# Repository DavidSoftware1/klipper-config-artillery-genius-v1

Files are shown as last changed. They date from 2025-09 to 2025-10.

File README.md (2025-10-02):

<p align="center">
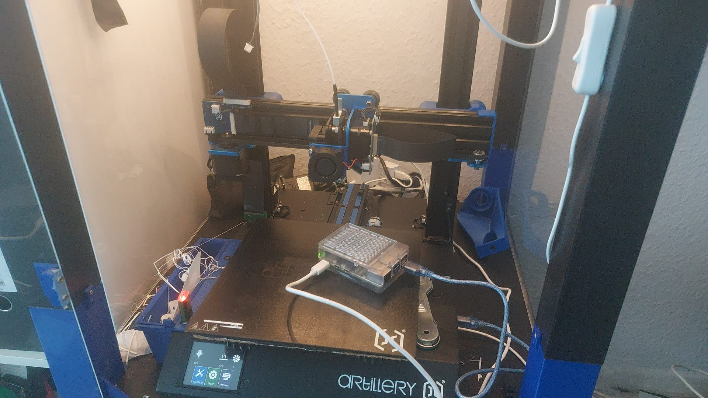
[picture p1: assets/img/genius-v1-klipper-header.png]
Artillery Genius Klipper Konfiguration Header
  
</p>

<h1 align="center">🚀 Artillery Genius V1 - Klipper Configuration</h1>

<p align="center">
  <strong>Complete Klipper setup for Artillery Genius V1 with MKS Gen L board</strong>
  <br/>
  <em>Mit deutschen Makros und Troubleshooting-Guide - Getestet und dokumentiert!</em>
</p>

<p align="center">
  
  
  
  
</p>

## 📖 Inhaltsverzeichnis

- [✨ Meine Erfolgsstory](#-meine-erfolgsstory)
- [🛠️ Komplette Installationsanleitung](#️-komplette-installationsanleitung)
- [🔧 Kritische Probleme & Lösungen](#-kritische-probleme--lösungen)
- [📁 Dateistruktur](#-dateistruktur)
- [🎮 Makros & Funktionen](#-makros--funktionen)
- [🐛 Problembehebung](#-problembehebung)
- [🤝 Mitwirken](#-mitwirken)

## ✨ Meine Erfolgsstory

### 🎯 Von Marlin zu Klipper: Komplette Hardware- und Performance-Optimierung für den Artillery Genius V1

Was als scheinbar unkompliziertes Upgrade begann, entwickelte sich zu einem tiefgreifenden Optimierungsprojekt, um das volle Potenzial des Artillery Genius V1 auszuschöpfen. Dieses Repository liefert die vollständige und getestete Klipper-Konfiguration für Boards mit dem MKS Gen L (ATmega2560).

Die Konfiguration löst nicht nur gängige Pin-Mapping-Probleme und behebt Inkompatibilitäten, sondern implementiert auch erweiterte Klipper-Funktionen (wie Input Shaping und Pressure Advance). Das Ergebnis ist eine dramatische Steigerung der Druckgeschwindigkeit, Stabilität und – vor allem – der Druckqualität, die weit über die Möglichkeiten der Standard-Marlin-Firmware hinausgeht. Holen Sie jetzt das Maximum aus Ihrem Artillery Genius V1 heraus.

### 📊 Meine Hardware
- **Drucker**: Artillery Genius V1
- **Mainboard**: MKS Gen L (ATmega2560)
- **Host**: Raspberry Pi 5
- **Schnittstelle**: USB über CH340 (COM6)

## 🛠️ Komplette Installationsanleitung

### Schritt 1: Basis-Setup & KIAUH
```bash
# System vorbereiten
sudo apt update && sudo apt upgrade -y
sudo apt-get install git -y

# KIAUH installieren
git clone https://github.com/th33xitus/kiauh.git
./kiauh/kiauh.sh

| **`Artillery-Genius-V1-Klipper/`** | | **Das Hauptverzeichnis des Projekts.** |
| ├── 📄 **`README.md`** | | **Diese Datei.** Beinhaltet die Installationsanleitung und Projektdetails. |
| ├── 📁 **`klipper/`** | | **Die Klipper-Core-Dateien.** |
| │ ├── 📄 `klipper.elf.hex` | MCU Firmware | Die fertig kompilierte Klipper-Firmware für das **MKS Gen L (ATmega2560) Mainboard** des Druckers. |
| │ └── 📁 `config/` | Klipper-Konfigurationen | Alle `.cfg`-Dateien zur Definition des Druckers. |
| │ ├── 📄 `printer.cfg` | **Hauptkonfiguration** | Definiert alle Pins, Kinematik und die kalibrierten Basiswerte. |
| │ ├── 📄 `macros.cfg` | Makros | Alle Makros wie `PRINT_START`, `END_PRINT` und sonstige Komfort-Funktionen. |
| │ ├── 📄 `end.cfg` | Druckende-Routinen | Routinen für den Abschluss eines Drucks. |
| │ └── 📄 `klipperscreen.cfg` | Display-Einstellungen | Voreinstellungen für das KlipperScreen-Interface. |
| ├── 📁 **`Prusa/`** | | **Slicer-Profile und Modelle.** |
| │ ├── 📄 `config.ini` | PrusaSlicer Profil | Das exportierte Profil, abgestimmt auf die Klipper-Geschwindigkeiten. |
| │ └── 📁 `3d/` | Modelle | Enthält Kalibrierungs-Modelle (`.stl`) und Projektdateien (`.3mf`). |
| ├── 📁 **`Marlin-bugfix-2.1.x/`** | | **Fallback-Firmware & Referenz.** |
| │ ├── 📄 `_Bootscreen.h` | Custom Bootscreen | Die Datei für den benutzerdefinierten Bootscreen-Startbildschirm. |
| │ └── 📄 `config.ini` | Marlin Basis-Config | Die Konfigurations-Dateien der ursprünglich verwendeten Marlin-Version. |
| └── 📁 **`assets/`** | | **Ressourcen und Dokumentation.** |
| └── 📄 `genius-v1-klipper-header.png` | Header-Bild | Das Bild, das oben in dieser README angezeigt wird. |
| └── 📄 `klipper-installation-doku.pdf` | Dokumentation | Die detaillierte Schritt-für-Schritt-Installationsanleitung im PDF-Format. |

## ⚡ Schnellstart

### 1. Klipper Installation
```bash
# Mit KIAUH installieren
git clone https://github.com/th33xitus/kiauh.git
./kiauh/kiauh.sh
# Wähle: Klipper → Moonraker → Mainsail

2. Firmware Flashen
bash

# Auf dem Raspberry Pi
cd ~/klipper
make menuconfig
# Micro-controller: Atmega AVR
# Processor: atmega2560
# Communication: UART0
make

# Flashen mit korrektem Device
make flash FLASH_DEVICE=/dev/serial/by-id/usb-1a86_USB_Serial-if00-port0

3. Konfiguration übernehmen
bash

# printer.cfg nach ~/printer_data/config/ kopieren
# Seriellen Pfad anpassen:
[mcu]
serial: /dev/serial/by-id/usb-1a86_USB_Serial-if00-port0

4. PrusaSlicer Profile

    Prusa/config.ini importieren

    G-code Flavor: Klipper

    Start/End G-code anpassen

🔧 Wichtige Fixes
🌀 Lüfter-Probleme Gelöst

Problem: Hotend-Lüfter (24V) reagierte nicht auf Pin ar7

Lösung: Korrekte Pin-Definition im [board_pins] Block:
ini

[board_pins arduino-mega]
aliases:
    ar5=PE3,    # Grüne LED
    ar6=PH3,    # Blaue LED  
    ar7=PH4,    # Hotend Lüfter (24V) - FIXED!
    ar9=PH6,    # Bauteil Lüfter

💡 LED-Steuerung

Problem: Neopixel flackerte unkontrolliert

Lösung: Einfache Output-Pins verwenden:

[output_pin green_led]
pin: ar5
value: 1

[output_pin blue_led]
pin: ar6  
value: 1

🎮 Makros & Funktionen
🏠 Smart Home
gcode

SMARTHOME          ; Homing 
MOVE_CENTER        ; Zur Bettmitte fahren

⏸️ Drucksteuerung
gcode

PAUSE              ; Sichere Unterbrechung
RESUME             ; Exaktes Fortsetzen
CANCEL_PRINT       ; Geordneter Abbruch

🎨 LED Status
gcode

LED_GRUEN          ; Bereit
LED_BLAU           ; Pausiert
LED_ROT            ; Fehler
LED_WEISS          ; Druck läuft

🔥 Kalibrierung
gcode

PID_EXTRUDER TARGET=210    ; Hotend PID
PID_BED TARGET=60          ; Heatbed PID

🔄 Marlin Fallback

Falls Klipper nicht wie gewünscht funktioniert, steht ein Marlin Fallback bereit:
Marlin Konfiguration

    Location: Marlin-bugfix-2.1.x/

    Custom Bootscreen in _Bootscreen.h

    Basierend auf: Offizielle Artillery Configs

Kompilieren mit PlatformIO
bash

cd Marlin-bugfix-2.1.x
platformio run -e mega2560
platformio run --target upload --upload-port COM6

🐛 Problembehebung
Häufige Probleme
Problem	Lösung
Serial Connection Failed	ls /dev/serial/by-id/ prüfen
Fans not working	24V am Hotend-Lüfter prüfen
LEDs flickering	[output_pin] statt [neopixel] verwenden
Flash Timeout	PrusaSlicer Firmware Flasher nutzen
Debug Commands
bash

# Serielle Verbindung prüfen
ls /dev/serial/by-id/

# Klipper Status
sudo service klipper status

# Logs anzeigen
tail -f ~/printer_data/logs/klippy.log

📸 Screenshots

(Füge hier deine Screenshots hinzu)

    Mainsail Dashboard

    Erfolgreicher Benchy-Druck

    LED-Steuerung in Aktion

    KlipperScreen Interface

🎯 Nächste Schritte

    Crowsnest für Webcam-Stream installieren

    Pressure Advance kalibrieren

    Input Shaping konfigurieren

    Timelapse mit Moonraker einrichten

🤝 Mitwirken

Fehler gefunden? Verbesserungsvorschläge?

    Repository forken

    Feature-Branch erstellen

    Änderungen committen

    Pull Request stellen

📄 Lizenz

MIT License - Frei verwendbar und modifizierbar für dein Artillery Genius V1.

Viel Erfolg beim Drucken! 🎉

Wenn diese Konfiguration dir geholfen hat, gib dem Repository einen ⭐ Stern!

Wichtiger Hinweis: Diese Konfiguration wurde speziell für den Artillery Genius V1 mit MKS Gen L Board entwickelt. Bei anderen Modellen sind Anpassungen notwendig.
text

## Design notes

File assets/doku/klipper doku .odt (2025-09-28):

sudo apt update && sudo apt upgrade -y && sudo apt autoremove -y &&sudo reboot

5min trotz lan 1000mbit

sudo apt-get install git -y

git clone https://github.com/th33xitus/kiauh.git
./kiauh/kiauh.sh

KIAUH v6.0.0-alpha1 is available now! |

| View Changelog: https://git.io/JnmlX |

| KIAUH v6 was completely rewritten from the ground up. |

| It's based on Python 3.8 and has many improvements. |

| NOTE: Version 6 is still in alpha, so bugs may occur! |

| Yet, your feedback and bug reports are very much |

| appreciated and will help finalize the release. |

| Would you like to try out KIAUH v6? |

| 1) Yes |

| 2) No |

| 3) Yes, remember my choice for next time |

| 4) No, remember my choice for next time |

| Q) Quit |

\=======================================================/

###### Select action:

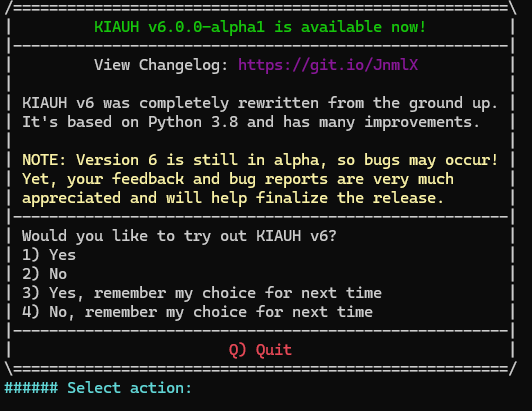
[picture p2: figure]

Gib bitte die Zahl 2 ein und drücke Enter

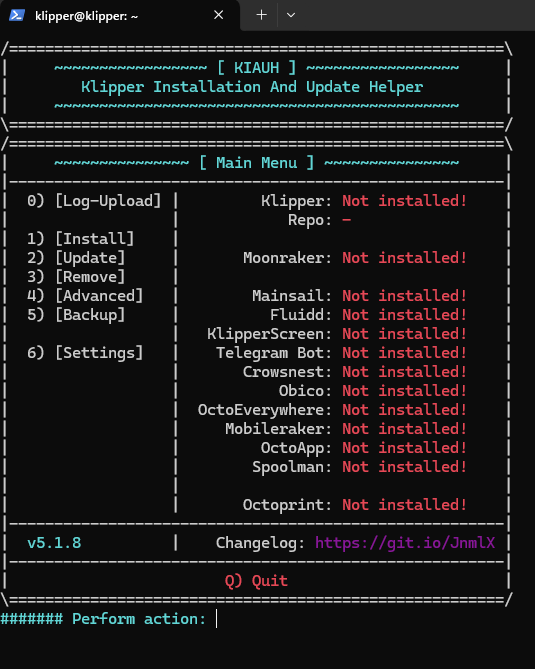
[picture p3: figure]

Nachdem du das getan hast, sollte das Hauptmenü erscheinen. Dort musst du dann 1) Install auswählen, um die Klipper-Komponenten zu installieren.

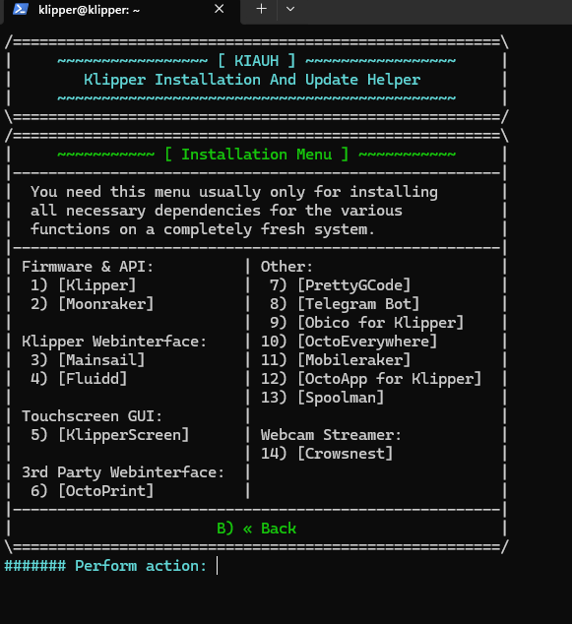
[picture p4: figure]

### Mein Tipp:

Um jetzt nicht den Überblick zu verlieren, installiere zuerst die absoluten Grundlagen: Klipper, Moonraker und Mainsail.

Gib also wie gesagt 1, ein und drücke Enter, um die Installation zu starten.

### Was bedeuten die anderen Optionen?

- 5) KlipperScreen: Dies ist für Leute, die einen Touchscreen direkt am Raspberry Pi angeschlossen haben, um den Drucker ohne Laptop oder Handy zu steuern. Da du eine Weboberfläche nutzen willst, brauchst du das nicht.
- 6) OctoPrint: Dies ist eine alternative Benutzeroberfläche zu Mainsail. Du solltest dich für eine der beiden entscheiden. Da wir bereits Mainsail empfohlen haben, kannst du OctoPrint ignorieren.
- 7) PrettyGCode: Eine Erweiterung für die Benutzeroberfläche, die dir den G-Code optisch aufbereitet. Ein nettes Gimmick.
- 8) Telegram Bot, 9) Obico, 10) OctoEverywhere, 11) Mobileraker, 12) OctoApp: Das sind alles Dienste, die dir helfen, deinen Drucker auch von unterwegs aus zu steuern und zu überwachen (oft mit Smartphone-Apps). Das sind Features für später.
- 13) Spoolman: Ein Tool, um deinen Filamentbestand zu verwalten. Das hat nichts direkt mit dem Drucken zu tun.
- 14) Crowsnest: Das ist der Webcam-Streamer, den du brauchst, um deine Pi-Kamera einzubinden. Das ist eine sehr nützliche Erweiterung, die wir später installieren können, wenn die Grundfunktionen laufen.

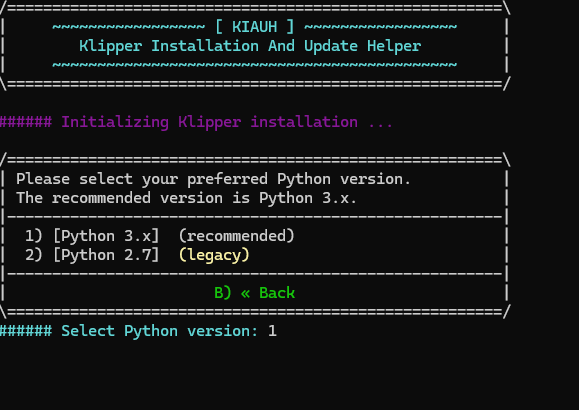
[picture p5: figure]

Python 3.x ist die richtige Wahl.

1 drunker haben wir 5min trotz lan 1000mbit

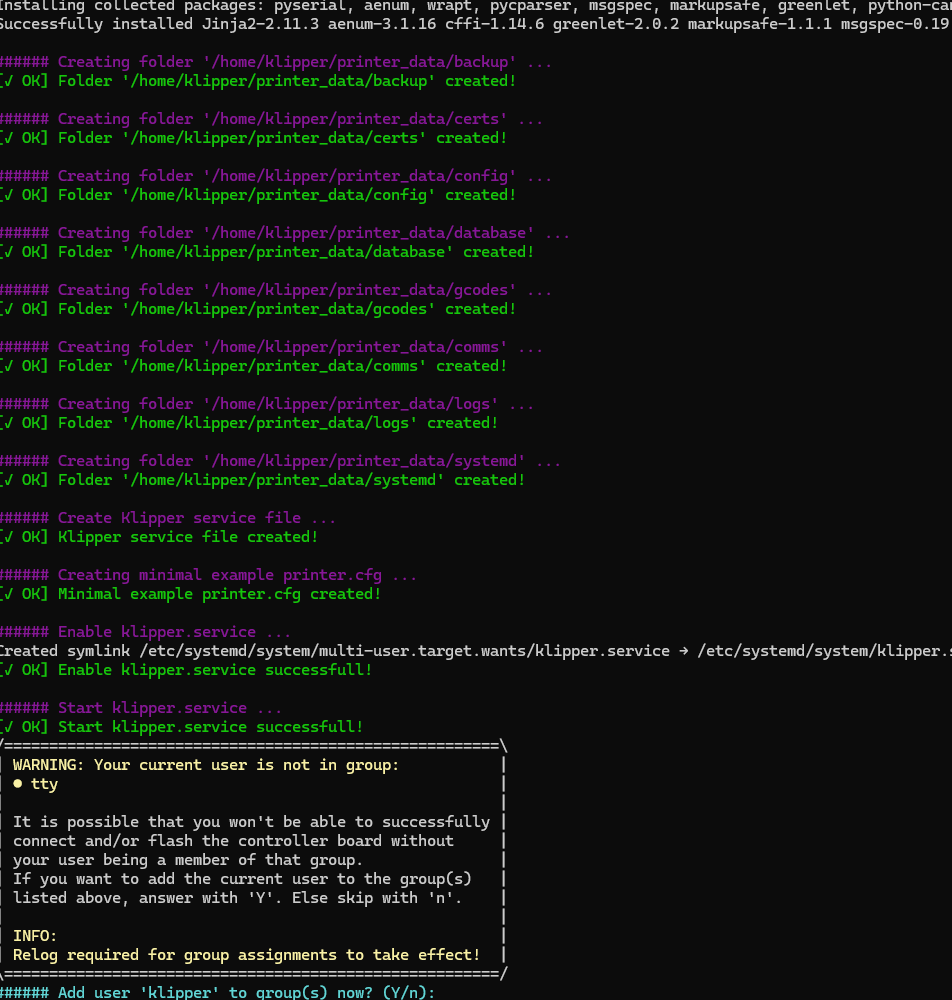
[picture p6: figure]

dvsvdv

a, gib Y ein und drücke Enter.

Das ist wichtig, damit der Klipper-Benutzer auf die Hardware-Schnittstelle deines Druckers zugreifen kann. Das Hinzufügen zu dieser Gruppe verhindert Verbindungsprobleme.

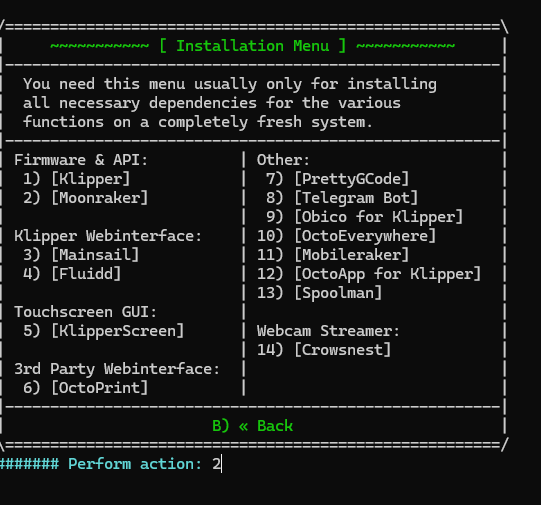
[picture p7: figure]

Moonraker (2): Dies ist die Schnittstelle (der "Dolmetscher"), die es deinem Pi ermöglicht, mit Klipper zu kommunizieren und ihm Befehle zu senden. Ohne Moonraker kann Klipper nicht gesteuert werden.

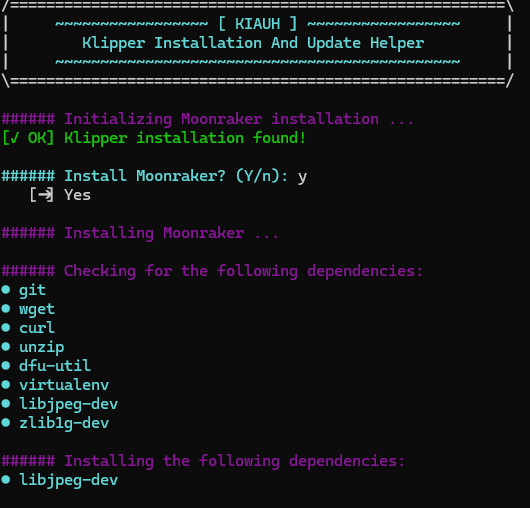
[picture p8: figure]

gfdgfdbsolut richtig! Jetzt kommt die Installation von Mainsail.

### Installation von Mainsail

Gib jetzt 3 ein und drücke Enter, um die Mainsail-Oberfläche zu installieren.

Moonraker ist die "Sprache", die Klipper und Mainsail verbindet. Mainsail ist das "Gesicht", das du im Browser siehst. Du brauchst beide, um deinen Drucker zu steuern.

Lass die Installation jetzt durchlaufen. Wenn sie abgeschlossen ist, sind alle notwendigen Komponenten auf deinem Raspberry Pi installiert.

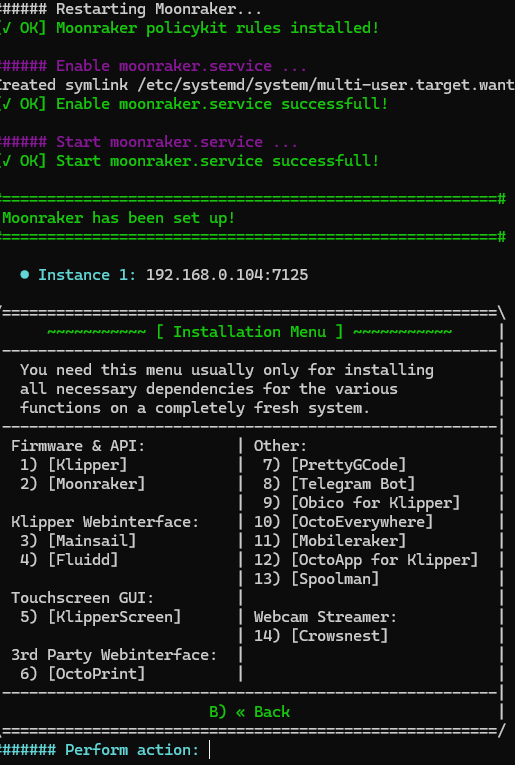
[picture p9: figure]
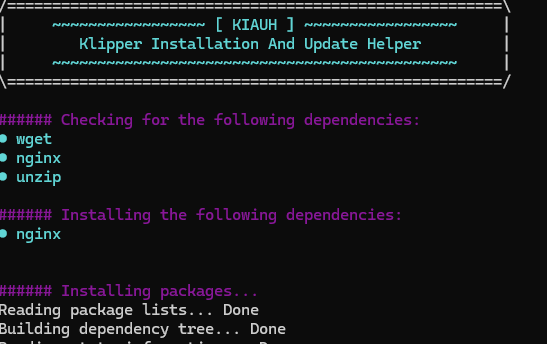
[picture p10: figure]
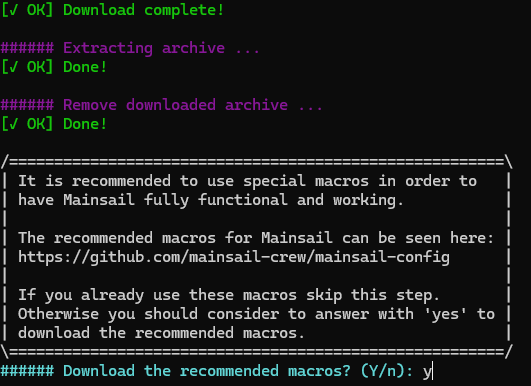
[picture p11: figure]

Y

Glückwunsch! Alle notwendigen Komponenten sind jetzt auf deinem Raspberry Pi installiert und einsatzbereit. Das ist der größte Teil der Arbeit.

Verlasse das KIAUH-Menü, indem du b enter q enter eingibst und Enter drückst.

cd ~/klipper

nun den drucker anstecken

ls /dev/serial/by-id/*

in meinem fall /dev/serial/by-id/usb-1a86_USB_Serial-if00-port0

Wenn alles korrekt angeschlossen ist, sollte jetzt ein Gerätename wie /dev/serial/by-id/usb-1a86_USB_Serial-if00-port0 erscheinen. Wenn du den Gerätenamen hast,

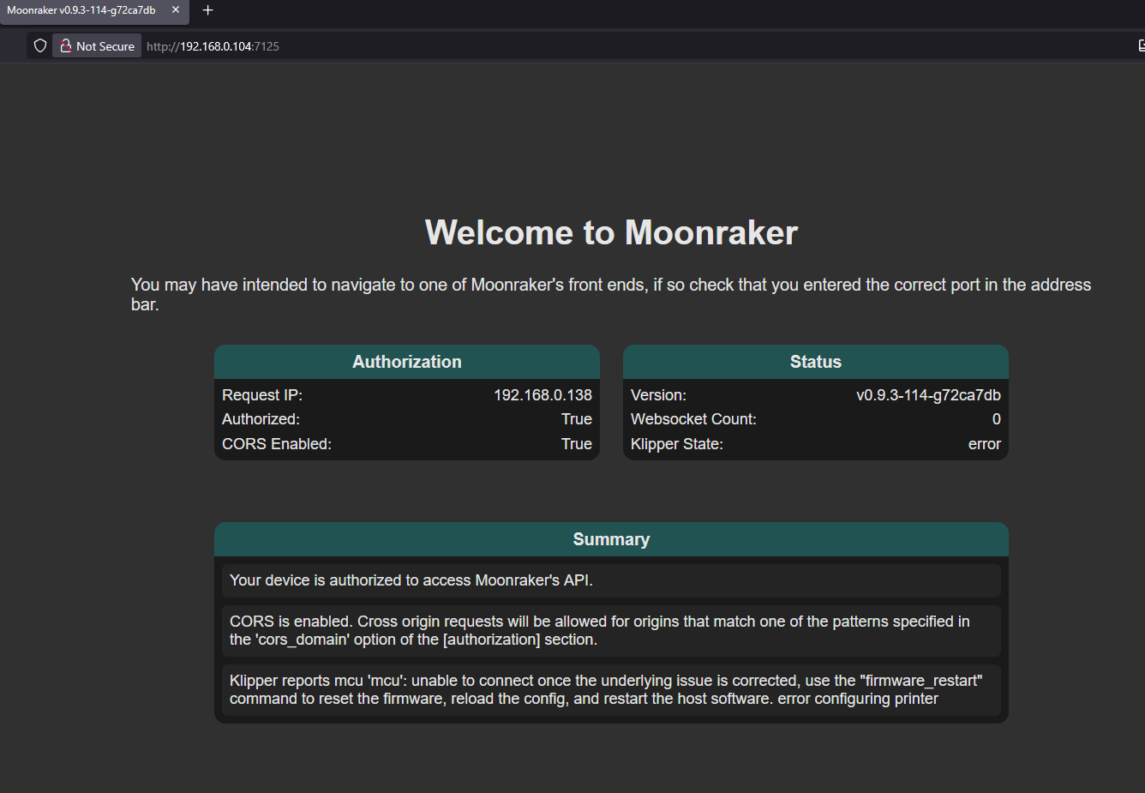
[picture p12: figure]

sudo service klipper stop

klipper@klipper:~/klipper $ make menuconfig

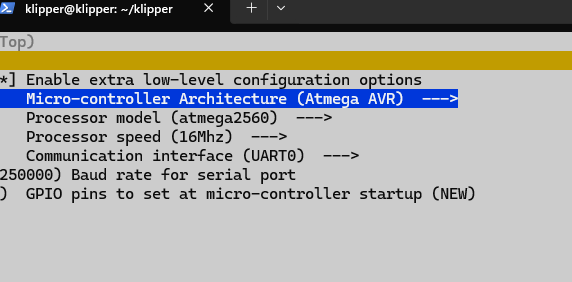
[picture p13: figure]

scsac

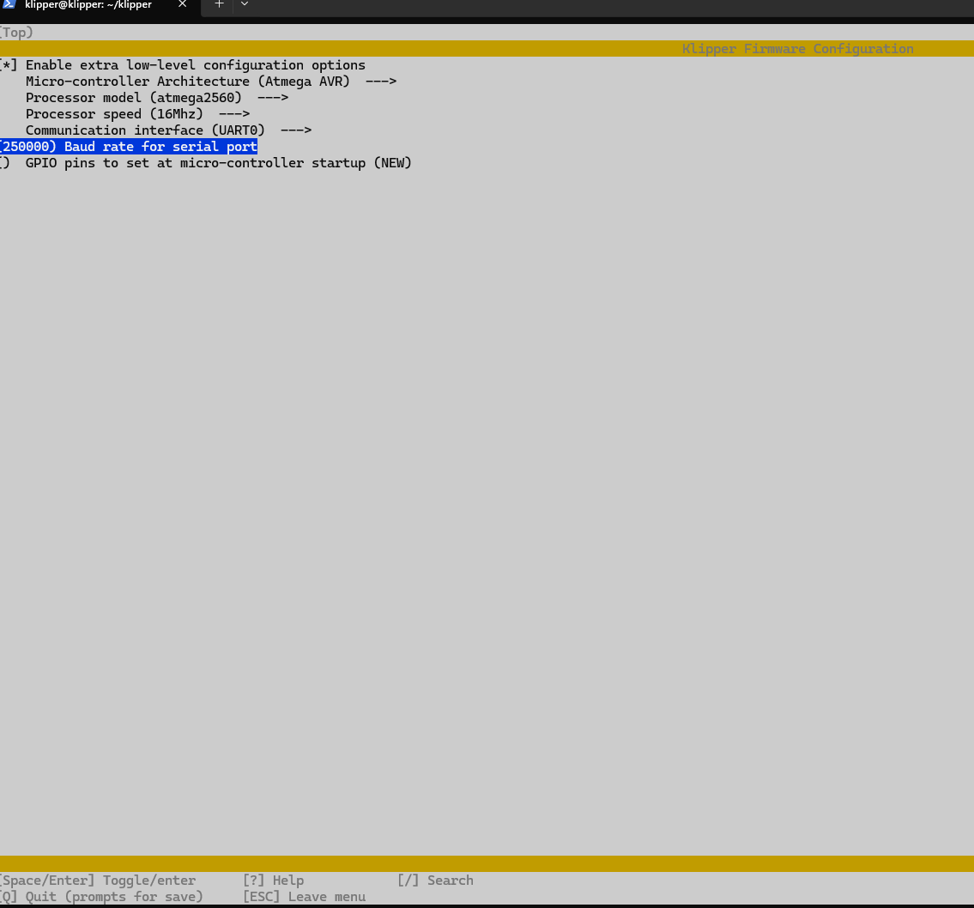
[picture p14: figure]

make

klipper@klipper:~/klipper $ ls /dev/serial/by-id/*

/dev/serial/by-id/usb-1a86_USB_Serial-if00-port0

make flash FLASH_DEVICE=/dev/serial/by-id/usb-1a86_USB_Serial-if00-port0

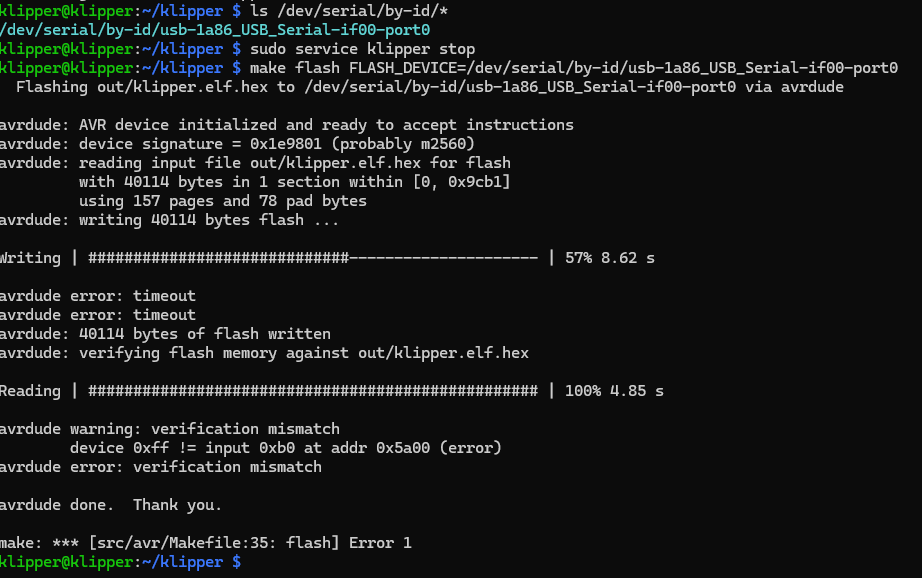
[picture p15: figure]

sudo service klipper start

sudo service klipper stop

avrdude -p atmega2560 -c wiring -P /dev/serial/by-id/usb-1a86_USB_Serial-if00-port0 -b115200 -D -U flash:w:out/klipper.elf.hex:i nop

sudo avrdude -p atmega2560 -c arduino -P /dev/serial/by-id/usb-1a86_USB_Serial-if00-port0 -b 115200 -U flash:w:out/klipper.elf.hex:i

sudo service klipper stop

klipper@klipper:~/klipper $ make flash FLASH_DEVICE=/dev/serial/by-id/usb-1a86_USB_Serial-if00-port0

Flashing out/klipper.elf.hex to /dev/serial/by-id/usb-1a86_USB_Serial-if00-port0 via avrdude

avrdude: AVR device initialized and ready to accept instructions

avrdude: device signature = 0x1e9801 (probably m2560)

avrdude: reading input file out/klipper.elf.hex for flash

with 40114 bytes in 1 section within [0, 0x9cb1]

using 157 pages and 78 pad bytes

avrdude: writing 40114 bytes flash ...

Writing | #############################--------------------- | 57% 8.62 s

avrdude error: timeout

avrdude error: timeout

avrdude: 40114 bytes of flash written

avrdude: verifying flash memory against out/klipper.elf.hex

Reading | ################################################## | 100% 4.85 s

avrdude warning: verification mismatch

device 0xff != input 0xb0 at addr 0x5a00 (error)

avrdude error: verification mismatch

avrdude done. Thank you.

make: *** [src/avr/Makefile:35: flash] Error 1

klipper@klipper:~/klipper $ sudo service klipper start

klipper@klipper:~/klipper $ make menuconfig

Loaded configuration '/home/klipper/klipper/.config'

No changes to save (for '/home/klipper/klipper/.config')

klipper@klipper:~/klipper $ avrdude -p atmega2560 -c wiring -P /dev/serial/by-id/usb-1a86_USB_Serial-if00-port0 -b115200 -D -U flash:w:out/klipper.elf.hex:i

avrdude: AVR device initialized and ready to accept instructions

avrdude: device signature = 0x1e9801 (probably m2560)

avrdude: reading input file out/klipper.elf.hex for flash

with 40114 bytes in 1 section within [0, 0x9cb1]

using 157 pages and 78 pad bytes

avrdude: writing 40114 bytes flash ...

Writing | ###############----------------------------------- | 29% 6.91 s

avrdude error: timeout

avrdude error: timeout

avrdude: 40114 bytes of flash written

avrdude: verifying flash memory against out/klipper.elf.hex

Reading | ################################################## | 100% 4.86 s

avrdude warning: verification mismatch

device 0xff != input 0x8e at addr 0x2f00 (error)

avrdude error: verification mismatch

avrdude done. Thank you.

klipper@klipper:~/klipper $ sudo avrdude -p atmega2560 -c arduino -P /dev/serial/by-id/usb-1a86_USB_Serial-if00-port0 -b 115200 -U flash:w:out/klipper.elf.hex:i

avrdude error: programmer is not responding

avrdude warning: attempt 1 of 10: not in sync: resp=0x00

avrdude error: programmer is not responding

avrdude warning: attempt 2 of 10: not in sync: resp=0x00

avrdude error: programmer is not responding

avrdude warning: attempt 3 of 10: not in sync: resp=0x00

avrdude error: programmer is not responding

ok jetzt mit video unter stützung von https://www.youtube.com/watch?v=7iQK6uSapJ0&t=485s

https://drive.google.com/file/d/1XB76P_dJ4WT7VyK5eNJ-UQJnxc4sq9R0/view

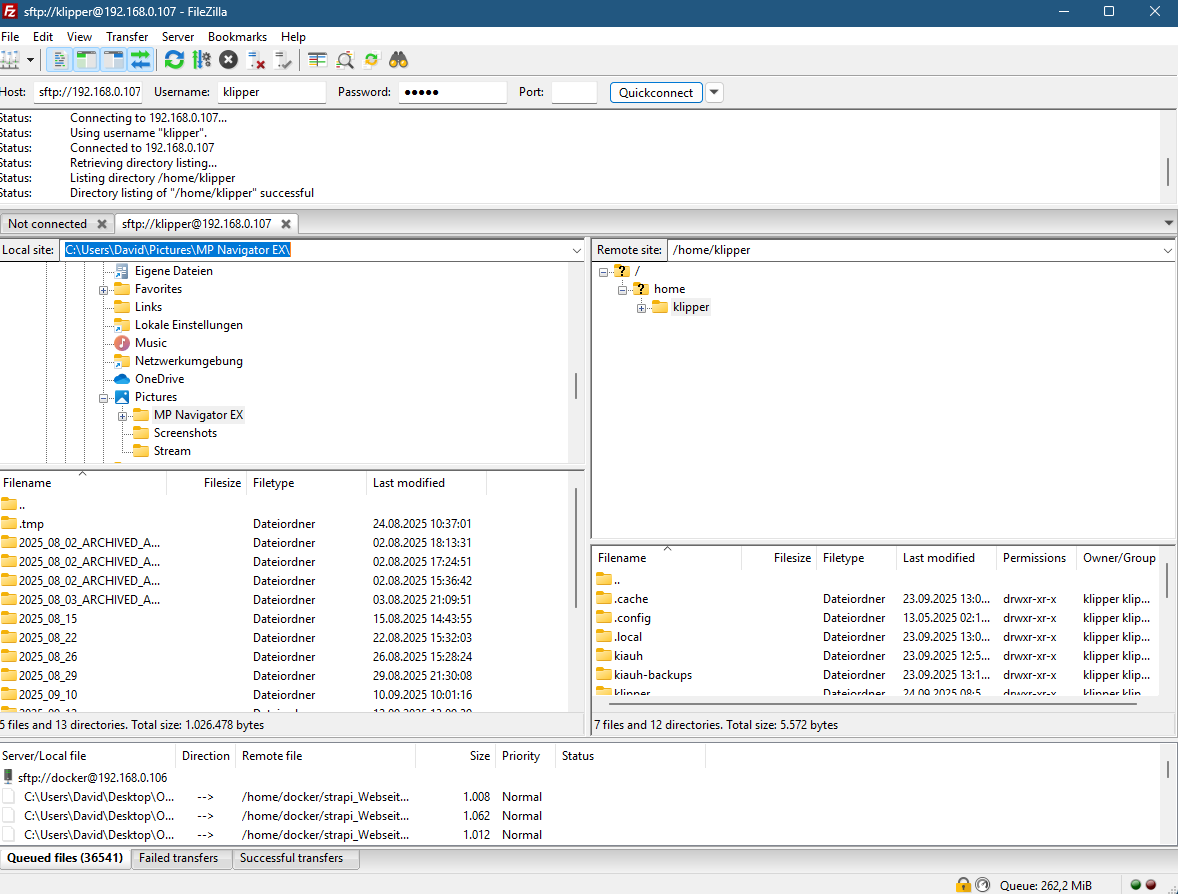
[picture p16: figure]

also file zilla auf und los git clone https://github.com/kliment/Printrun.git https://www.youtube.com/watch?v=7iQK6uSapJ0&t=485s

drucker an pc anschliessen vill erfolg ?

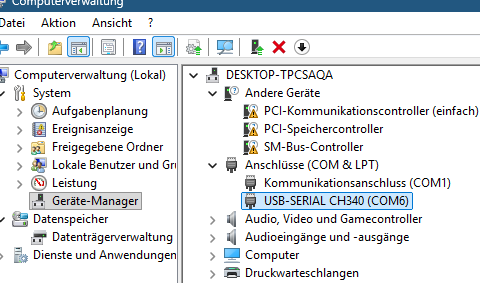
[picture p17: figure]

Cdc

also com 4 also avrdude -p atmega2560 -c arduino -P COM4 -b 115200 -U flash:w:klipper.elf.hex:i

also vs code aud plattform io installiren datai in ordner schmeissen offenen vertrauen dann quik acsess →miscellanous plattform io core cli cd .platformio

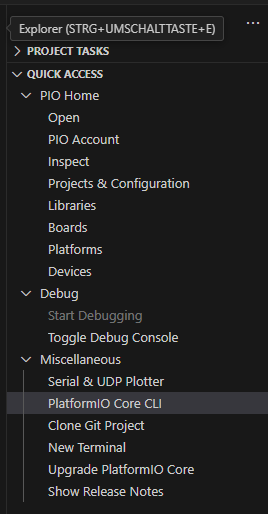
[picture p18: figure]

PS C:\Users\David\.platformio> ls

Directory: C:\Users\David\.platformio

Mode LastWriteTime Length Name

d---- 24.09.2025 10:48 .cache

d---- 24.09.2025 10:45 packages

d---- 24.09.2025 10:45 penv

d---- 24.09.2025 10:44 python3

-a--- 24.09.2025 10:45 177 appstate.json

PS C:\Users\David\.platformio> cd packages

PS C:\Users\David\.platformio\packages> ls

Directory: C:\Users\David\.platformio\packages

Mode LastWriteTime Length Name

d---- 24.09.2025 10:45 contrib-piohome

PS C:\Users\David\.platformio\packages> also nach installation von pio platform install atmelavr

S C:\Users\David\.platformio\packages> pio platform install atmelavr

WARNING: This command is deprecated and will be removed in the next releases.

Please use `pio pkg install` instead.

Platform Manager: Installing atmelavr

Downloading [####################################] 100%

Unpacking [####################################] 100%

Platform Manager: atmelavr@5.1.0 has been installed!

Tool Manager: Installing platformio/toolchain-atmelavr @ ~1.70300.0

Downloading [####################################] 100%

Unpacking [####################################] 100%

Tool Manager: toolchain-atmelavr@1.70300.191015 has been installed!

PS C:\Users\David\.platformio\packages> & "C:\Users\David\.platformio\packages\toolchain-atmelavr\bin\avrdude.exe" -C "C:\Users\David\.platformio\packages\toolchain-atmelavr\etc\avrdude.conf" -v -p atmega2560 -c arduino -P COM4 -b 115200 -U flash:w:C:\Users\David\Desktop\klipper\firmware.elf.hex:i

&: The term 'C:\Users\David\.platformio\packages\toolchain-atmelavr\bin\avrdude.exe' is not recognized as a name of a cmdlet, function, script file, or executable program.

Check the spelling of the name, or if a path was included, verify that the path is correct and try again.

PS C:\Users\David\.platformio\packages>

ls

Directory: C:\Users\David\.platformio\packages\toolchain-atmelavr

Mode LastWriteTime Length Name

d---- 24.09.2025 11:00 avr

d---- 24.09.2025 11:00 bin

d---- 24.09.2025 11:00 i686-w64-mingw32

d---- 24.09.2025 11:00 include

d---- 24.09.2025 11:00 lib

d---- 24.09.2025 11:00 libexec

-a--- 24.09.2025 11:00 185 .piopm

-a--- 13.12.2024 14:43 390 package.json

PS C:\Users\David\.platformio\packages\toolchain-atmelavr> cd bin

PS C:\Users\David\.platformio\packages\toolchain-atmelavr\bin> .\avrdude.exe -C "C:\Users\David\.platformio\packages\toolchain-atmelavr\etc\avrdude.conf" -v -p atmega2560 -c arduino -P COM4 -b 115200 -U flash:w:C:\Users\David\Desktop\klipper\firmware.elf.hex:i

antwort .\avrdude.exe: The term '.\avrdude.exe' is not recognized as a name of a cmdlet, function, script file, or executable program.

Check the spelling of the name, or if a path was included, verify that the path is correct and try again.

Auch im cmd probiert Microsoft Windows [Version 10.0.26100.6584]

(c) Microsoft Corporation. Alle Rechte vorbehalten.

C:\Users\David>cd "C:\Users\David\.platformio\packages\toolchain-atmelavr\bin"

C:\Users\David\.platformio\packages\toolchain-atmelavr\bin>avrdude.exe -C "C:\Users\David\.platformio\packages\toolchain-atmelavr\etc\avrdude.conf" -v -p atmega2560 -c arduino -P COM4 -b 115200 -U flash:w:C:\Users\David\Desktop\klipper\firmware.elf.hex:i

Der Befehl "avrdude.exe" ist entweder falsch geschrieben oder

konnte nicht gefunden werden.

C:\Users\David\.platformio\packages\toolchain-atmelavr\bin>ls

Der Befehl "ls" ist entweder falsch geschrieben oder

konnte nicht gefunden werden.

C:\Users\David\.platformio\packages\toolchain-atmelavr\bin>dir

Volume in Laufwerk C: hat keine Bezeichnung.

Volumeseriennummer: A4CE-B767

Verzeichnis von C:\Users\David\.platformio\packages\toolchain-atmelavr\bin

24.09.2025 11:00 <DIR> .

24.09.2025 11:00 <DIR> ..

12.03.2019 10:30 608.256 avr-addr2line.exe

12.03.2019 10:30 630.784 avr-ar.exe

12.03.2019 10:30 815.104 avr-as.exe

12.03.2019 10:46 877.568 avr-c++.exe

12.03.2019 10:30 605.696 avr-c++filt.exe

12.03.2019 10:46 876.032 avr-cpp.exe

12.03.2019 10:30 35.840 avr-elfedit.exe

12.03.2019 10:46 877.568 avr-g++.exe

12.03.2019 10:46 874.496 avr-gcc-7.3.0.exe

12.03.2019 10:46 52.736 avr-gcc-ar.exe

12.03.2019 10:46 52.736 avr-gcc-nm.exe

12.03.2019 10:46 53.248 avr-gcc-ranlib.exe

12.03.2019 10:46 874.496 avr-gcc.exe

12.03.2019 10:46 438.272 avr-gcov-dump.exe

12.03.2019 10:46 483.328 avr-gcov-tool.exe

12.03.2019 10:46 523.776 avr-gcov.exe

12.03.2019 10:53 3.299.840 avr-gdb.exe

12.03.2019 10:30 667.648 avr-gprof.exe

12.03.2019 10:30 1.102.848 avr-ld.bfd.exe

12.03.2019 10:30 1.102.848 avr-ld.exe

12.03.2019 10:50 1.944 avr-man

12.03.2019 10:30 617.472 avr-nm.exe

12.03.2019 10:30 766.976 avr-objcopy.exe

12.03.2019 10:30 888.832 avr-objdump.exe

12.03.2019 10:30 630.784 avr-ranlib.exe

12.03.2019 10:30 456.192 avr-readelf.exe

12.03.2019 10:30 616.448 avr-size.exe

12.03.2019 10:30 608.256 avr-strings.exe

12.03.2019 10:30 767.488 avr-strip.exe

12.03.2019 10:53 978.432 libiconv-2.dll

12.03.2019 10:53 51.694 libwinpthread-1.dll

31 Datei(en), 21.237.638 Bytes

2 Verzeichnis(se), 45.501.906.944 Bytes frei

C:\Users\David\.platformio\packages\toolchain-atmelavr\bin>

klappt auch nicht wir weden nun Arduino IDE testen

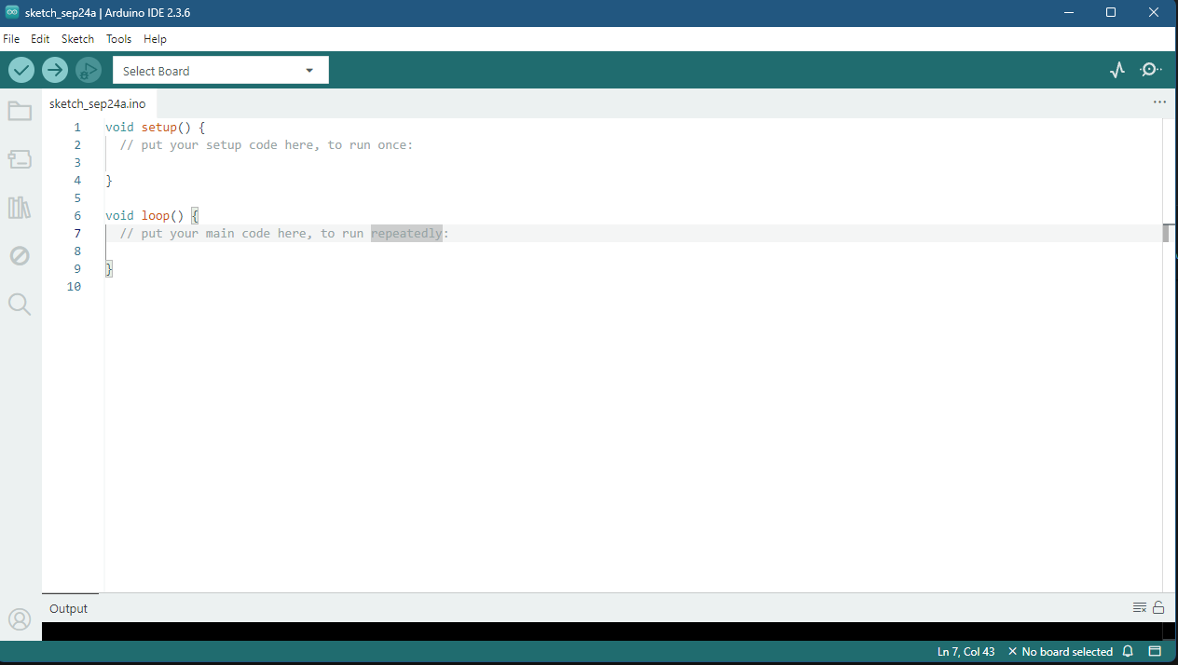
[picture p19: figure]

https://www.arduino.cc/en/software/

wo wir dabai sind der step back ist ja auch immer ein guter plan

https://github.com/MarlinFirmware/Configurations/tree/bugfix-2.1.x/config/examples/Artillery/Genius/V1

wichtig !

NotPlatformIOProjectError: Not a PlatformIO project. `platformio.ini` file has not been found in current working directory (C:\Users\David\Downloads\Marlin-bugfix-2.1.x). To initialize new project please use `platformio project init` command

platformio run

_Bootscreen.h

mega2560 SUCCESS 00:00:44.029

================================================================================================= 1 succeeded in 00:00:44.029 =================================================================================================

PS C:\Users\David\Downloads\Marlin-bugfix-2.1.x\Marlin-bugfix-2.1.x>

platformio run --target upload --upload-port COM6

nvironment Status Duration

mega2560 SUCCESS 00:00:30.954

================================================================================================= 1 succeeded in 00:00:30.954 =================================================================================================

PS C:\Users\David\Downloads\Marlin-bugfix-2.1.x\Marlin-bugfix-2.1.x>

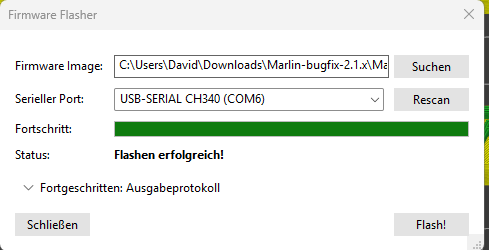
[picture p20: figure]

des

also versuchen wir mal die hex datai per prusa dadrauf zu bekommen !

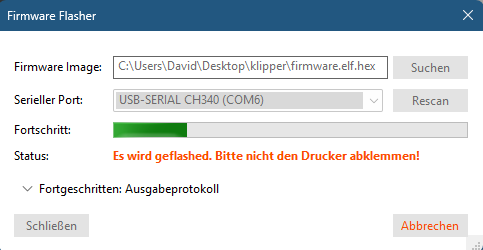
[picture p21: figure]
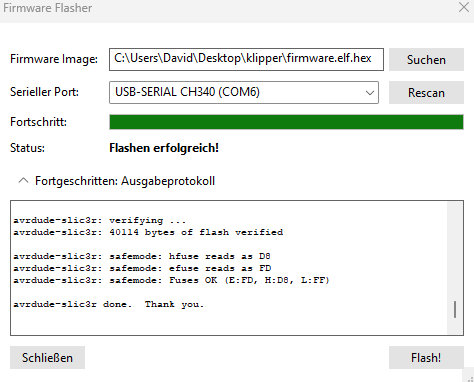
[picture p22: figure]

Dsdv

bfbfdb

http://klipper.local/ oder http://192.168.0.107/

so web ist erreich bar nun das config file wo es ja bekanntlich die meisten probleme gibt

Klipper reports: ERROR

Unable to parse option 'max_velocity' in section 'printer'

Once the underlying issue is corrected, use the "RESTART"

command to reload the config and restart the host software.

Printer is halted

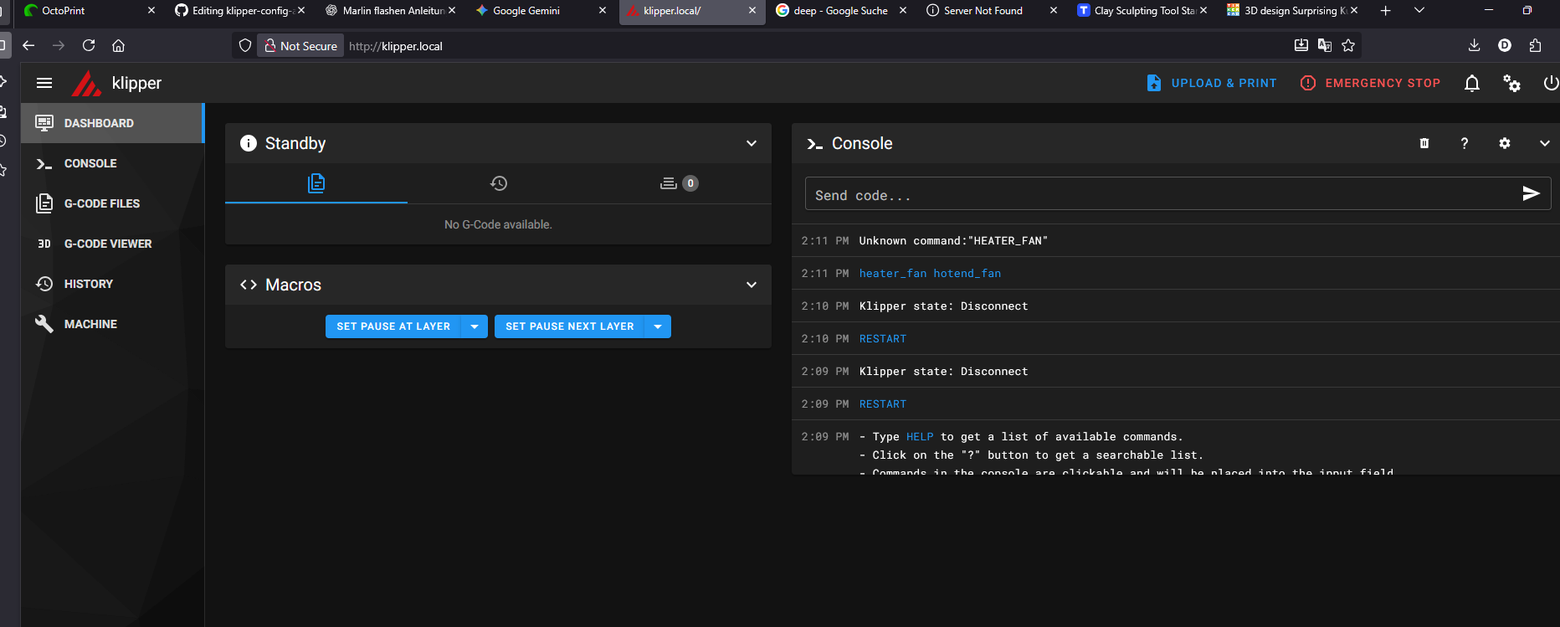
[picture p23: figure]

https://github.com/MarlinFirmware/Configurations/tree/bugfix-2.1.x

#####################################################################
# Artillery Genius V1 - MKS Gen L Board (ATmega2560) - FINAL CONFIG
#####################################################################

[include mainsail.cfg]

[mcu]
# DEIN KORREKTER SERIAL-PFAD
serial: /dev/serial/by-id/usb-1a86_USB_Serial-if00-port0

[printer]
kinematics: cartesian
max_velocity: 300
max_accel: 2000
max_z_velocity: 50
max_z_accel: 100
square_corner_velocity: 5.0

#####################################################################
# AXEN
#####################################################################

[stepper_x]
step_pin: ar54
dir_pin: ar55
enable_pin: !ar38
microsteps: 16
rotation_distance: 40.0
endstop_pin: ^!ar3
position_endstop: 0
position_max: 220
homing_speed: 50

[stepper_y]
step_pin: ar60
dir_pin: ar61
enable_pin: !ar56
microsteps: 16
rotation_distance: 40.0
endstop_pin: ^!ar14
position_endstop: 0
position_max: 220
homing_speed: 50
homing_positive_dir: False

[stepper_z]
step_pin: ar46
dir_pin: !ar48
enable_pin: !ar62
microsteps: 16
rotation_distance: 8
endstop_pin: ^!ar18
position_endstop: 0
position_max: 250
position_min: -2
homing_speed: 10
second_homing_speed: 3

#####################################################################
# EXTRUDER
#####################################################################

[extruder]
step_pin: ar26
dir_pin: ar28
enable_pin: !ar24
microsteps: 16
rotation_distance: 7.49
nozzle_diameter: 0.400
filament_diameter: 1.750
max_extrude_only_distance: 500

heater_pin: ar10
sensor_type: EPCOS 100K B57560G104F
sensor_pin: analog13
control: pid
pid_kp: 23.509
pid_ki: 1.438
pid_kd: 96.092
min_temp: 0
max_temp: 300

#####################################################################
# HEATBED
#####################################################################

[heater_bed]
heater_pin: ar8
sensor_type: EPCOS 100K B57560G104F
# Der Fehler ist hier: Pin 'analog14' muss vom Alias-Block definiert werden.
sensor_pin: analog14
control: pid
pid_kp: 42.365
pid_ki: 0.545
pid_kd: 822.940
min_temp: 0
max_temp: 130

#####################################################################
# LÜFTER
#####################################################################

[fan] # Bauteillüfter
pin: ar9
off_below: 0.1

[heater_fan hotend_fan] # Hotend-Lüfter
pin: ar6
heater: extruder
heater_temp: 50.0

#####################################################################
# FILAMENT SENSOR
#####################################################################

[filament_switch_sensor filament]
switch_pin: ar19
pause_on_runout: True
runout_gcode: M117 Filament runout
insert_gcode: M117 Filament insert

#####################################################################
# LEDS
#####################################################################

[neopixel hotend_led]
pin: ar7
chain_count: 3
color_order: GRB
initial_RED: 1.0
initial_GREEN: 1.0
initial_BLUE: 1.0

#####################################################################
# SD & HOMING
#####################################################################

[virtual_sdcard]
path: /home/klipper/printer_data/gcodes
on_error_gcode: CANCEL_PRINT

[safe_z_home]
home_xy_position: 110,110
z_hop: 10
speed: 50

[bed_screws]
screw1: 35,35
screw1_name: front left
screw2: 185,35
screw2_name: front right
screw3: 185,185
screw3_name: back right
screw4: 35,185
screw4_name: back left
speed: 50

#####################################################################
# WICHTIG: PIN-DEFINITIONEN (Aliase)
#####################################################################

[board_pins arduino-mega]
aliases:
ar0=PE0, ar1=PE1, ar2=PE4, ar3=PE5, ar4=PG5,
ar5=PE3, ar6=PH3, ar7=PH4, ar8=PH5, ar9=PH6,
ar10=PB4, ar11=PB5, ar12=PB6, ar13=PB7, ar14=PJ1,
ar15=PJ0, ar16=PH1, ar17=PH0, ar18=PD3, ar19=PD2,
ar20=PD1, ar21=PD0, ar22=PA0, ar23=PA1, ar24=PA2,
ar25=PA3, ar26=PA4, ar27=PA5, ar28=PA6, ar29=PA7,
ar30=PC7, ar31=PC6, ar32=PC5, ar33=PC4, ar34=PC3,
ar35=PC2, ar36=PC1, ar37=PC0, ar38=PD7, ar39=PG2,
ar40=PG1, ar41=PG0, ar42=PL7, ar43=PL6, ar44=PL5,
ar45=PL4, ar46=PL3, ar47=PL2, ar48=PL1, ar49=PL0,
ar50=PB3, ar51=PB2, ar52=PB1, ar53=PB0, ar54=PF0,
ar55=PF1, ar56=PF2, ar57=PF3, ar58=PF4, ar59=PF5,
ar60=PF6, ar61=PF7, ar62=PK0, ar63=PK1, ar64=PK2,
ar65=PK3, ar66=PK4, ar67=PK5, ar68=PK6, ar69=PK7,
analog0=PF0, analog1=PF1, analog2=PF2, analog3=PF3, analog4=PF4,
analog5=PF5, analog6=PF6, analog7=PF7, analog8=PK0, analog9=PK1,
analog10=PK2, analog11=PK3, analog12=PK4, analog13=PK5, analog14=PK6,
analog15=PK7

#*# DO NOT EDIT THIS BLOCK OR BELOW. The contents are auto-generated.

Großartig! Ein Benchy ist der perfekte erste Druck, um deine neue Klipper-Einrichtung zu testen.

Bevor du den Druck startest, musst du sicherstellen, dass dein Drucker optimal eingestellt ist, um Fehler oder Schäden zu vermeiden.

## 1. Wichtige Vorbereitung

### ⚠️ Z-Offset final einstellen

Da der Drucker noch nicht gedruckt hat, ist dies der allerwichtigste Schritt, um zu verhindern, dass die Düse in das Druckbett kratzt!

1. Homing: Sende G28 in die Konsole.
2. Offset finden: Verwende die manuelle Steuerung, um die Düse so weit abzusenken, bis ein Stück Papier zwischen Düse und Bett leicht hakt.
3. Offset speichern: Wenn du den Wert (z. B. -0.25) gefunden hast, speichere ihn dauerhaft mit:
  G-Code

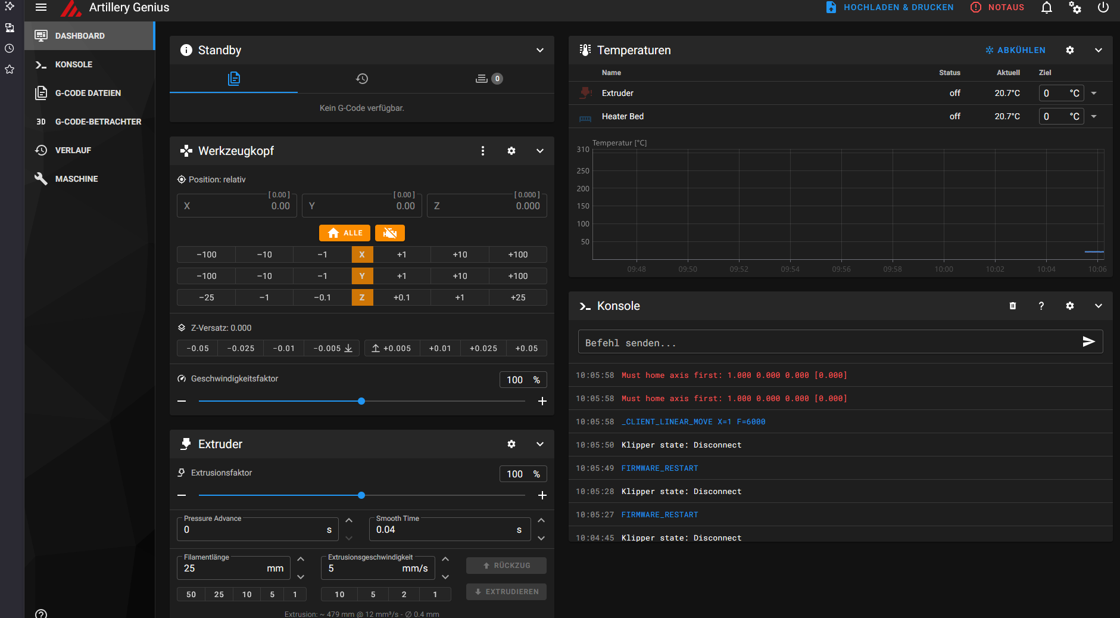
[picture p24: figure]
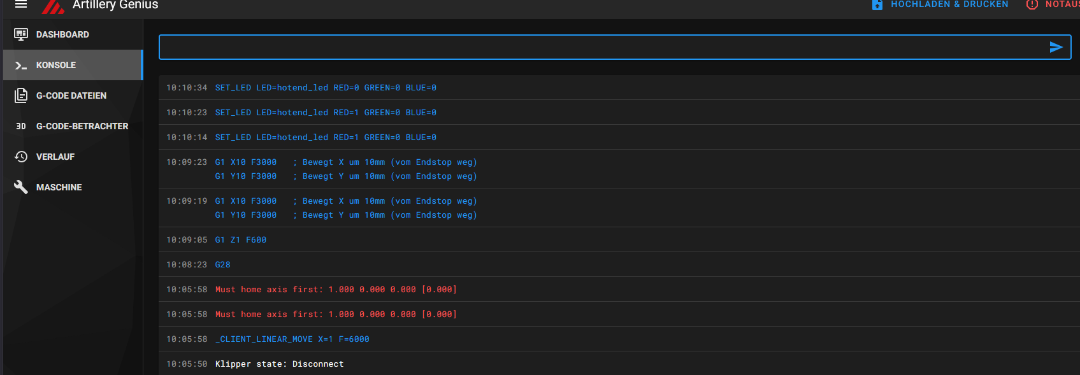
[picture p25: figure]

klappt irgenwie doch über die oberfläche

hotend_fan pin: ar7// aber keine power ? 24V oder ?

ar5 grüne led

ar6 blaue led

Bauteillüfter pin: ar9

Dann hast du jetzt:

- Hotend-Lüfter und Bauteillüfter korrekt auf eigenen Pins → laufen sauber.
- RGB-SMD-LEDs als [output_pin] → nur an/aus, kein Flackern.
- Makros für LED-Farben bereit → schnelle Kontrolle über GCode.

G28
M104 S200
M140 S60
Filament Sensor filament: filament detected

11:26:31

QUERY_FILAMENT_SENSOR SENSOR=filament

PRINT_START BED_TEMP=[first_layer_bed_temperature] EXTRUDER_TEMP=[first_layer_temperature]

END_PRINT

FILAMENT_UNLOADFilament EntladenFunktioniert korrekt: heizt auf 230°C, fährt relativ 100 mm zurück, dann zurück auf absolut (G90).FILAMENT_LOADFilament LadenFunktioniert korrekt: heizt auf 230°C, fährt relativ 125 mm vor, macht einen kleinen Retract von 2 mm und geht dann zurück auf absolut (G90).LED_GRUENLED GrünKorrekt: Schaltet Grün an, Rot und Blau aus.SMART_HOMEHoming mit ParkenLogik-Problem: Führt G28 aus. Direkt danach fährt es auf X3 Y3 Z5 und schaltet die LED grün. Die Park- und LED-Aktion sollte aus diesem Makro entfernt werden, da es nur fürs Homing zuständig sein sollte (siehe Empfehlung unten).FAHRE_AUF_NEUTRALE_POSITIONNeutrale PositionRedundant: Ruft SMART_HOME auf, was bereits parkt. Fährt dann von X3 Y3 Z5 erneut zu X3 Y3 Z5 und dann zu Z10.

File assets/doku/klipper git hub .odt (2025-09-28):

# Kompletter Klipper Installationsguide mit KIAUH – Für Blog und GitHub

## Einleitung

Willkommen zur umfassenden Anleitung zur Installation von Klipper mit dem Klipper Installation And Update Helper (KIAUH). Dieser Guide führt dich Schritt für Schritt durch den gesamten Prozess – perfekt für Einsteiger!

## Vorbereitung des Systems

### Systemaktualisierung durchführen

bash

sudo apt update && sudo apt upgrade -y && sudo apt autoremove -y && sudo reboot

Hinweis: Die Aktualisierung kann trotz Gigabit-LAN-Verbindung etwa 5 Minuten dauern – das ist normal!

### Git installieren

bash

sudo apt-get install git -y

## KIAUH einrichten

### Repository klonen und starten

bash

git clone https://github.com/th33xitus/kiauh.git

./kiauh/kiauh.sh

### KIAUH Version auswählen

Bei der ersten Ausführung erscheint eine wichtige Abfrage:

Wähle Option 2 (Nein), da die v6.0.0-alpha1 noch in der Alpha-Phase ist und Bugs enthalten könnte.

## Das Hauptmenü verstehen

Nach der Versionauswahl erscheint das Hauptmenü:

Wähle Option 1) Install, um mit der Installation der Klipper-Komponenten zu beginnen.

## 📋 Installationsmenü – Was bedeutet was?

Hier siehst du das komplette Angebot an Installationsoptionen:

### Mein Tipp für den Anfang

Um den Überblick nicht zu verlieren, installiere zuerst die absoluten Grundlagen in dieser Reihenfolge:

1. Klipper (Option 1) – Die Hauptfirmware
2. Moonraker (Option 2) – Die API-Schnittstelle
3. Mainsail (Option 3) – Die Weboberfläche

### Erklärung der anderen Optionen

- 5) KlipperScreen: Für Touchscreen-Nutzer (nicht benötigt bei reiner Weboberfläche)
- 6) OctoPrint: Alternative zu Mainsail – entscheide dich für eine Oberfläche
- 7) PrettyGCode: Visuelle G-Code-Darstellung (nettes Feature für später)
- 8-12) Telegram Bot, Obico, etc.: Fernzugriff und Monitoring (Features für später)
- 13) Spoolman: Filament-Management (separates Tool)
- 14) Crowsnest: Webcam-Streaming (sehr nützlich, aber erst nach Grundinstallation)

## Schritt-für-Schritt Installation

### 1. Klipper installieren (Option 1)

Python Version auswählen:

Wähle Option 1 (Python 3.x) – das ist die empfohlene Version.

Anzahl der Klipper-Instanzen:

Wähle 1, es sei denn, du betreibst mehrere Drucker gleichzeitig.

Wichtiger Schritt – Benutzer zu Gruppe hinzufügen:

Wenn gefragt wird: "Add user 'klipper' to group(s) now?"
Antworte mit Y (Ja)!

Das ist wichtig, damit der Klipper-Benutzer auf die Hardware-Schnittstelle deines Druckers zugreifen kann und Verbindungsprobleme vermieden werden.

### 2. Moonraker installieren (Option 2)

Moonraker ist der "Dolmetscher", der die Kommunikation zwischen deinem Pi und Klipper ermöglicht. Ohne Moonraker kann Klipper nicht gesteuert werden.

Wähle Option 2 und bestätige mit Y. Nach erfolgreicher Installation siehst du:

Die angezeigte IP-Adresse ist dein Zugang zum System!

### 3. Mainsail installieren (Option 3)

Mainsail ist das "Gesicht" deines Druckers – die Weboberfläche, die du im Browser siehst.

Abhängigkeiten werden automatisch installiert:

Empfohlene Makros installieren:

Antworte mit Y (Ja), um die empfohlenen Makros für volle Funktionalität zu installieren.

## ✅ Installation abschließen

### KIAUH verlassen

Gib q ein und drücke Enter, um KIAUH zu verlassen.

## 🔧 Drucker verbinden und testen

### Serielle Verbindung prüfen

Wechsle ins Klipper-Verzeichnis und schließe deinen Drucker an:

bash

cd ~/klipper

ls /dev/serial/by-id/*

Erwartete Ausgabe:

text

/dev/serial/by-id/usb-1a86_USB_Serial-if00-port0

Merke dir diesen Gerätenamen – du brauchst ihn für die spätere Konfiguration!

### Webinterface testen

Öffne deinen Browser und navigiere zu:

text

http://[deine-pi-ip-adresse]:7125

Du solltest folgende Seite sehen:

## 🚨 Wichtige Hinweise und Fehlerbehebung

### Häufiger Anfängerfehler

Falls du eine Fehlermeldung wie "mcu 'mcu': unable to connect" siehst:

1. Prüfe die USB-Verbindung zwischen Pi und Drucker
2. Stelle sicher, dass der richtige serielle Port in der printer.cfg eingetragen ist
3. Führe firmware_restart aus

### Dienste neustarten

bash

sudo service klipper restart

sudo service moonraker restart

## 🎯 Nächste Schritte nach der Installation

1. Konfiguration anpassen: Bearbeite printer.cfg für deinen spezifischen Drucker
2. Webcam einrichten: Installiere Crowsnest (Option 14) für Live-Streaming
3. Slicer konfigurieren: Richte deinen Slicer für Klipper ein
4. Erweiterungen hinzufügen: Telegram Bot, Obico, etc. für erweiterte Funktionen

## 💡 Tipps für ein reibungsloses Setup

- Backup erstellen: Bevor du größere Änderungen vornimmst
- Einen Schritt nach dem anderen: Nicht alle Erweiterungen gleichzeitig installieren
- Community nutzen: Bei Problemen helfen die Klipper-Foren und Discord-Server

## Fazit

Glückwunsch! Du hast jetzt alle Grundkomponenten erfolgreich installiert:

- ✅ Klipper – Die Hochleistungs-Firmware
- ✅ Moonraker – Die Kommunikations-API
- ✅ Mainsail – Die moderne Weboberfläche

Das Fundament steht! Jetzt kannst du mit der Konfiguration für deinen spezifischen Drucker beginnen.

Viel Erfolg beim Drucken mit Klipper! 🚀

Dieser Guide wurde mit KIAUH v5.1.8 erstellt. Für Updates besuche das KIAUH GitHub Repository (https://github.com/th33xitus/kiauh). Feedback und Verbesserungsvorschläge sind willkommen!

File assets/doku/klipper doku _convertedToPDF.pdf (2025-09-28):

sudo apt update && sudo apt upgrade -y && sudo apt autoremove -y &&sudo reboot
5min trotz lan 1000mbit
sudo apt-get install git -y

git clone https://github.com/th33xitus/kiauh.git./kiauh/kiauh.sh

KIAUH v6.0.0-alpha1 is available now! | |-------------------------------------------------------|
| | View Changelog: https://git.io/JnmlX | |
| KIAUH v6 was completely rewritten from the ground up. | | It's based on Python 3.8 and has many improvements. |
| NOTE: Version 6 is still in alpha, so bugs may occur! |
| Yet, your feedback and bug reports are very much | |
| appreciated and will help finalize the release. | |
| Would you like to try out KIAUH v6? | |
| 1) Yes | |
| 2) No | |
| 3) Yes, remember my choice for next time | |
| 4) No, remember my choice for next time | |
| | Q) Quit | |
\=======================================================/ ###### Select action:


Gib bitte die Zahl 2 ein und drücke Enter


Nachdem du das getan hast, sollte das Hauptmenü erscheinen. Dort musst du dann 1) Install auswählen, um die Klipper-Komponenten zu installieren.


Mein Tipp:
Um jetzt nicht den Überblick zu verlieren, installiere zuerst die absoluten Grundlagen: Klipper, Moonraker und Mainsail.
Gib also wie gesagt 1, ein und drücke Enter, um die Installation zu starten.

Was bedeuten die anderen Optionen?
- 5) KlipperScreen: Dies ist für Leute, die einen Touchscreen direkt am Raspberry Pi angeschlossen haben, um den Drucker ohne Laptop oder Handy zu steuern. Da du eine Weboberfläche nutzen willst, brauchst du das nicht.

- 6) OctoPrint: Dies ist eine alternative Benutzeroberfläche zu Mainsail. Du solltest dich für eine der beiden entscheiden. Da wir bereits Mainsail empfohlen haben, kannst du OctoPrint ignorieren.
- 7) PrettyGCode: Eine Erweiterung für die Benutzeroberfläche, die dir den G-Code optisch aufbereitet. Ein nettes Gimmick.
- 8) Telegram Bot, 9) Obico, 10) OctoEverywhere, 11) Mobileraker,
12) OctoApp: Das sind alles Dienste, die dir helfen, deinen Drucker auch von unterwegs aus zu steuern und zu überwachen (oft mit Smartphone-Apps). Das sind Features für später.
- 13) Spoolman: Ein Tool, um deinen Filamentbestand zu verwalten. Das hat nichts direkt mit dem Drucken zu tun.
- 14) Crowsnest: Das ist der Webcam-Streamer, den du brauchst, um deine Pi-Kamera einzubinden. Das ist eine sehr nützliche Erweiterung, die wir später installieren können, wenn die Grundfunktionen laufen.


Python 3.x ist die richtige Wahl.

1 drunker haben wir 5min trotz lan 1000mbit


dvsvdv

a, gib Y ein und drücke Enter.
Das ist wichtig, damit der Klipper-Benutzer auf die Hardware-Schnittstelle deines Druckers zugreifen kann. Das Hinzufügen zu dieser Gruppe verhindert Verbindungsprobleme.


Moonraker (2): Dies ist die Schnittstelle (der "Dolmetscher"), die es deinem Pi ermöglicht, mit Klipper zu kommunizieren und ihm Befehle zu senden. Ohne Moonraker kann Klipper nicht gesteuert werden.


gfdgfdbsolut richtig! Jetzt kommt die Installation von Mainsail.
Installation von Mainsail

Gib jetzt 3 ein und drücke Enter, um die Mainsail-Oberfläche zu installieren. Moonraker ist die "Sprache", die Klipper und Mainsail verbindet. Mainsail ist das "Gesicht", das du im Browser siehst. Du brauchst beide, um deinen Drucker zu steuern.
Lass die Installation jetzt durchlaufen. Wenn sie abgeschlossen ist, sind alle notwendigen Komponenten auf deinem Raspberry Pi installiert.


Y
Glückwunsch! Alle notwendigen Komponenten sind jetzt auf deinem Raspberry Pi installiert und einsatzbereit. Das ist der größte Teil der Arbeit.

Verlasse das KIAUH-Menü, indem du b enter q enter eingibst und Enter drückst.

cd ~/klipper

nun den drucker anstecken

ls /dev/serial/by-id/*

in meinem fall /dev/serial/by-id/usb-1a86_USB_Serial-if00-port0

Wenn alles korrekt angeschlossen ist, sollte jetzt ein Gerätename wie /dev/serial/by-id/usb-1a86_USB_Serial-if00-port0 erscheinen. Wenn du den Gerätenamen hast,


sudo service klipper stop klipper@klipper:~/klipper $ make menuconfig


scsac


make
klipper@klipper:~/klipper $ ls /dev/serial/by-id/*

/dev/serial/by-id/usb-1a86_USB_Serial-if00-port0

make flash FLASH_DEVICE=/dev/serial/by-id/usb-1a86_USB_Serial-if00-port0


sudo service klipper start

sudo service klipper stop

avrdude -p atmega2560 -c wiring -P /dev/serial/by-id/usb-1a86_USB_Serial-if00-port0 -b115200 -D -U flash:w:out/klipper.elf.hex:i nop
sudo avrdude -p atmega2560 -c arduino -P /dev/serial/by-id/usb-1a86_USB_Serial-if00-port0 -b 115200 -U flash:w:out/klipper.elf.hex:i

sudo service klipper stop
klipper@klipper:~/klipper $ make flash FLASH_DEVICE=/dev/serial/by-id/usb-1a86_USB_Serial-if00-port0 Flashing out/klipper.elf.hex to /dev/serial/by-id/usb-1a86_USB_Serial-if00-port0 via avrdude

avrdude: AVR device initialized and ready to accept instructions
avrdude: device signature = 0x1e9801 (probably m2560)
avrdude: reading input file out/klipper.elf.hex for flash
with 40114 bytes in 1 section within [0, 0x9cb1]
using 157 pages and 78 pad bytes
avrdude: writing 40114 bytes flash ...

Writing | #############################--------------------- | 57%
8.62 s

avrdude error: timeout
avrdude error: timeout
avrdude: 40114 bytes of flash written
avrdude: verifying flash memory against out/klipper.elf.hex

Reading |
### | 100% 4.85 s

avrdude warning: verification mismatch
device 0xff != input 0xb0 at addr 0x5a00 (error)
avrdude error: verification mismatch

avrdude done. Thank you.

make: *** [src/avr/Makefile:35: flash] Error 1 klipper@klipper:~/klipper $ sudo service klipper start klipper@klipper:~/klipper $ make menuconfig
Loaded configuration '/home/klipper/klipper/.config'
No changes to save (for '/home/klipper/klipper/.config') klipper@klipper:~/klipper $ avrdude -p atmega2560 -c wiring -P /dev/serial/by-id/usb-1a86_USB_Serial-if00-port0 -b115200 -D -U flash:w:out/klipper.elf.hex:i

avrdude: AVR device initialized and ready to accept instructions avrdude: device signature = 0x1e9801 (probably m2560) avrdude: reading input file out/klipper.elf.hex for flash
with 40114 bytes in 1 section within [0, 0x9cb1]
using 157 pages and 78 pad bytes
avrdude: writing 40114 bytes flash ...
Writing | ###############----------------------------------- | 29% 6.91 s

avrdude error: timeout
avrdude error: timeout
avrdude: 40114 bytes of flash written
avrdude: verifying flash memory against out/klipper.elf.hex

Reading |
### | 100% 4.86 s

avrdude warning: verification mismatch
device 0xff != input 0x8e at addr 0x2f00 (error)
avrdude error: verification mismatch

avrdude done. Thank you.

klipper@klipper:~/klipper $ sudo avrdude -p atmega2560 -c arduino -P /dev/serial/by-id/usb-1a86_USB_Serial-if00-port0 -b 115200 -U flash:w:out/klipper.elf.hex:i
avrdude error: programmer is not responding
avrdude warning: attempt 1 of 10: not in sync: resp=0x00 avrdude error: programmer is not responding
avrdude warning: attempt 2 of 10: not in sync: resp=0x00 avrdude error: programmer is not responding
avrdude warning: attempt 3 of 10: not in sync: resp=0x00
avrdude error: programmer is not responding

ok jetzt mit video unter stützung von https://www.youtube.com/watch?v=7iQK6uSapJ0&t=485s (https://www.youtube.com/watch?v=7iQK6uSapJ0&t=485s)
https://drive.google.com/file/d/1XB76P_dJ4WT7VyK5eNJ-UQJnxc4sq9R0/view


also file zilla auf und los git clone https://github.com/kliment/Printrun.githttps://www.youtube.com/watch?v=7iQK6uSapJ0&t=485s


drucker an pc anschliessen vill erfolg ?

Cdc

also com 4 also avrdude -p atmega2560 -c arduino -P COM4 -b 115200 -U flash:w:klipper.elf.hex:i

also vs code aud
plattform io installiren
datai in ordner
schmeissen offenen
vertrauen dann quik
acsess →miscellanous
plattform io core cli cd
.platformio
PS C:

\Users\David\.platformio> ls

Directory: C:\Users\David\.platformio

Mode | LastWriteTime | Length Name
d---- | 24.09.2025 10:48 | .cache
d---- | 24.09.2025 10:45 | packages
d---- | 24.09.2025 10:45 | penv
d---- | 24.09.2025 10:44 | python3
-a--- | 24.09.2025 10:45 | 177 appstate.json

PS C:\Users\David\.platformio> cd packages
PS C:\Users\David\.platformio\packages> ls

Directory: C:\Users\David\.platformio\packages

Mode | LastWriteTime | Length Name
d---- | 24.09.2025 10:45 | contrib-piohome

PS C:\Users\David\.platformio\packages> also nach installation von pio platform install atmelavr

S C:\Users\David\.platformio\packages> pio platform install atmelavr

WARNING: This command is deprecated and will be removed in the next releases.
Please use `pio pkg install` instead.

Platform Manager: Installing atmelavr
Downloading [####################################] 100%
Unpacking [####################################] 100%
Platform Manager: atmelavr@5.1.0 has been installed!
Tool Manager: Installing platformio/toolchain-atmelavr @ ~1.70300.0 Downloading [####################################] 100%
Unpacking [####################################] 100%
Tool Manager: toolchain-atmelavr@1.70300.191015 has been installed!
PS C:\Users\David\.platformio\packages> & "C: \Users\David\.platformio\packages\toolchain-atmelavr\bin\avrdude.exe" -C "C: \Users\David\.platformio\packages\toolchain-atmelavr\etc\avrdude.conf" -v -p atmega2560 -c arduino -P COM4 -b 115200 -U flash:w:C: \Users\David\Desktop\klipper\firmware.elf.hex:i
&: The term 'C:\Users\David\.platformio\packages\toolchain-atmelavr\bin\avrdude.exe' is not recognized as a name of a cmdlet, function, script file, or executable program.
Check the spelling of the name, or if a path was included, verify that the path is correct and try again.
PS C:\Users\David\.platformio\packages>

ls

Directory: C:\Users\David\.platformio\packages\toolchain-atmelavr

Mode | LastWriteTime | Length Name
d---- | 24.09.2025 11:00 | avr
d---- | 24.09.2025 11:00 | bin
d---- | 24.09.2025 11:00 | i686-w64-mingw32
d---- | 24.09.2025 11:00 | include
d---- | 24.09.2025 11:00 | lib
d---- | 24.09.2025 11:00 | libexec
-a--- | 24.09.2025 11:00 | 185 .piopm
-a--- | 13.12.2024 14:43 | 390 package.json

PS C:\Users\David\.platformio\packages\toolchain-atmelavr> cd bin
PS C:\Users\David\.platformio\packages\toolchain-atmelavr\bin> . \avrdude.exe -C "C:\Users\David\.platformio\packages\toolchain-atmelavr\etc\avrdude.conf" -v -p atmega2560 -c arduino -P COM4 -b 115200 -U flash:w:C:\Users\David\Desktop\klipper\firmware.elf.hex:i

antwort .\avrdude.exe: The term '.\avrdude.exe' is not recognized as a name of a cmdlet, function, script file, or executable program.
Check the spelling of the name, or if a path was included, verify that the path is correct and try again.

Auch im cmd probiert Microsoft Windows [Version 10.0.26100.6584]
(c) Microsoft Corporation. Alle Rechte vorbehalten.

C:\Users\David>cd "C:\Users\David\.platformio\packages\toolchain-atmelavr\bin"

C:\Users\David\.platformio\packages\toolchain-atmelavr\bin>avrdude.exe -C "C:\Users\David\.platformio\packages\toolchain-atmelavr\etc\avrdude.conf" -v -p atmega2560 -c arduino -P COM4 -b 115200 -U flash:w:C: \Users\David\Desktop\klipper\firmware.elf.hex:i
Der Befehl "avrdude.exe" ist entweder falsch geschrieben oder
konnte nicht gefunden werden.

C:\Users\David\.platformio\packages\toolchain-atmelavr\bin>ls Der Befehl "ls" ist entweder falsch geschrieben oder
konnte nicht gefunden werden.

C:\Users\David\.platformio\packages\toolchain-atmelavr\bin>dir
Volume in Laufwerk C: hat keine Bezeichnung.
Volumeseriennummer: A4CE-B767

Verzeichnis von C:\Users\David\.platformio\packages\toolchain-atmelavr\bin

24.09.2025 11:00 <DIR> | .
24.09.2025 11:00 <DIR> | ..
12.03.2019 10:30 | 608.256 avr-addr2line.exe

12.03.2019 10:30 | 630.784 avr-ar.exe
12.03.2019 10:30 | 815.104 avr-as.exe
12.03.2019 10:46 | 877.568 avr-c++.exe
12.03.2019 10:30 | 605.696 avr-c++filt.exe
12.03.2019 10:46 | 876.032 avr-cpp.exe
12.03.2019 10:30 | 35.840 avr-elfedit.exe
12.03.2019 10:46 | 877.568 avr-g++.exe
12.03.2019 10:46 | 874.496 avr-gcc-7.3.0.exe
12.03.2019 10:46 | 52.736 avr-gcc-ar.exe
12.03.2019 10:46 | 52.736 avr-gcc-nm.exe
12.03.2019 10:46 | 53.248 avr-gcc-ranlib.exe
12.03.2019 10:46 | 874.496 avr-gcc.exe
12.03.2019 10:46 | 438.272 avr-gcov-dump.exe
12.03.2019 10:46 | 483.328 avr-gcov-tool.exe
12.03.2019 10:46 | 523.776 avr-gcov.exe
12.03.2019 10:53 | 3.299.840 avr-gdb.exe
12.03.2019 10:30 | 667.648 avr-gprof.exe
12.03.2019 10:30 | 1.102.848 avr-ld.bfd.exe
12.03.2019 10:30 | 1.102.848 avr-ld.exe
12.03.2019 10:50 | 1.944 avr-man
12.03.2019 10:30 | 617.472 avr-nm.exe
12.03.2019 10:30 | 766.976 avr-objcopy.exe
12.03.2019 10:30 | 888.832 avr-objdump.exe
12.03.2019 10:30 | 630.784 avr-ranlib.exe
12.03.2019 10:30 | 456.192 avr-readelf.exe
12.03.2019 10:30 | 616.448 avr-size.exe
12.03.2019 10:30 | 608.256 avr-strings.exe
12.03.2019 10:30 | 767.488 avr-strip.exe
12.03.2019 10:53 | 978.432 libiconv-2.dll
12.03.2019 10:53 | 51.694 libwinpthread-1.dll
31 Datei(en), | 21.237.638 Bytes
2 Verzeichnis(se), 45.501.906.944 Bytes frei

C:\Users\David\.platformio\packages\toolchain-atmelavr\bin>

klappt auch nicht wir weden nun Arduino IDE testen


https://www.arduino.cc/en/software/

wo wir dabai sind der step back ist ja auch immer ein guter plan

https://github.com/MarlinFirmware/Configurations/tree/bugfix-2.1.x/config/examples/Artillery/Genius/V1 (https://github.com/MarlinFirmware/Configurations/tree/bugfix-2.1.x/config/examples/Artillery/Genius/V1)

wichtig !
NotPlatformIOProjectError: Not a PlatformIO project. `platformio.ini` file has not been found in current working directory (C: \Users\David\Downloads\Marlin-bugfix-2.1.x). To initialize new project please use `platformio project init` command

platformio run

_Bootscreen.h

mega2560 SUCCESS 00:00:44.029 =============================================== =============================================== === 1 succeeded in 00:00:44.029 =============================================== =============================================== ===
PS C:\Users\David\Downloads\Marlin-bugfix-2.1.x\Marlin-bugfix-2.1.x>


platformio run --target upload --upload-port COM6 nvironment Status Duration
mega2560 SUCCESS 00:00:30.954 =============================================== =============================================== === 1 succeeded in 00:00:30.954 =============================================== =============================================== ===
PS C:\Users\David\Downloads\Marlin-bugfix-2.1.x\Marlin-bugfix-2.1.x>

des


also

versuchen wir mal die hex datai per prusa dadrauf zu bekommen ! Dsdv

bfbfdb

http://klipper.local/ oder http://192.168.0.107/

so web ist erreich bar nun das config file wo es ja bekanntlich die meisten probleme gibt

Klipper reports: ERROR

Unable to parse option 'max_velocity' in section 'printer'

Once the underlying issue is corrected, use the "RESTART" command to reload the config and restart the host software. Printer is halted


https://github.com/MarlinFirmware/Configurations/tree/bugfix-2.1.x

# Artillery Genius V1 - MKS Gen L Board (ATmega2560) - FINAL CONFIG ############################################### ######################

[include mainsail.cfg]

[mcu]
# DEIN KORREKTER SERIAL-PFAD

serial: /dev/serial/by-id/usb-1a86_USB_Serial-if00-port0

[printer]
kinematics: cartesian
max_velocity: 300
max_accel: 2000
max_z_velocity: 50
max_z_accel: 100
square_corner_velocity: 5.0
# AXEN

[stepper_x]
step_pin: ar54
dir_pin: ar55
enable_pin: !ar38
microsteps: 16
rotation_distance: 40.0
endstop_pin: ^!ar3
position_endstop: 0
position_max: 220
homing_speed: 50

[stepper_y]
step_pin: ar60
dir_pin: ar61
enable_pin: !ar56
microsteps: 16
rotation_distance: 40.0
endstop_pin: ^!ar14
position_endstop: 0
position_max: 220
homing_speed: 50
homing_positive_dir: False

[stepper_z]
step_pin: ar46
dir_pin: !ar48
enable_pin: !ar62
microsteps: 16
rotation_distance: 8
endstop_pin: ^!ar18
position_endstop: 0
position_max: 250
position_min: -2
homing_speed: 10
second_homing_speed: 3
# EXTRUDER

[extruder]
step_pin: ar26
dir_pin: ar28
enable_pin: !ar24
microsteps: 16
rotation_distance: 7.49
nozzle_diameter: 0.400
filament_diameter: 1.750 max_extrude_only_distance: 500

heater_pin: ar10
sensor_type: EPCOS 100K B57560G104F sensor_pin: analog13
control: pid
pid_kp: 23.509
pid_ki: 1.438
pid_kd: 96.092
min_temp: 0
max_temp: 300
# HEATBED

[heater_bed]
heater_pin: ar8
sensor_type: EPCOS 100K B57560G104F
# Der Fehler ist hier: Pin 'analog14' muss vom Alias-Block definiert werden. sensor_pin: analog14

control: pid
pid_kp: 42.365
pid_ki: 0.545
pid_kd: 822.940
min_temp: 0
max_temp: 130
# LÜFTER

[fan] # Bauteillüfter
pin: ar9
off_below: 0.1

[heater_fan hotend_fan] # Hotend-Lüfter pin: ar6
heater: extruder
heater_temp: 50.0
# FILAMENT SENSOR

[filament_switch_sensor filament]

switch_pin: ar19
pause_on_runout: True
runout_gcode: M117 Filament runout
insert_gcode: M117 Filament insert
# LEDS

[neopixel hotend_led]
pin: ar7
chain_count: 3
color_order: GRB
initial_RED: 1.0
initial_GREEN: 1.0
initial_BLUE: 1.0
# SD & HOMING

[virtual_sdcard]
path: /home/klipper/printer_data/gcodes
on_error_gcode: CANCEL_PRINT

[safe_z_home]
home_xy_position: 110,110
z_hop: 10
speed: 50

[bed_screws]
screw1: 35,35
screw1_name: front left
screw2: 185,35
screw2_name: front right
screw3: 185,185
screw3_name: back right
screw4: 35,185
screw4_name: back left
speed: 50
# WICHTIG: PIN-DEFINITIONEN (Aliase) ############################################### ######################

[board_pins arduino-mega]

aliases:
ar0=PE0, ar1=PE1, ar2=PE4, ar3=PE5, ar4=PG5, ar5=PE3, ar6=PH3, ar7=PH4, ar8=PH5, ar9=PH6, ar10=PB4, ar11=PB5, ar12=PB6, ar13=PB7, ar14=PJ1, ar15=PJ0, ar16=PH1, ar17=PH0, ar18=PD3, ar19=PD2, ar20=PD1, ar21=PD0, ar22=PA0, ar23=PA1, ar24=PA2, ar25=PA3, ar26=PA4, ar27=PA5, ar28=PA6, ar29=PA7, ar30=PC7, ar31=PC6, ar32=PC5, ar33=PC4, ar34=PC3, ar35=PC2, ar36=PC1, ar37=PC0, ar38=PD7, ar39=PG2, ar40=PG1, ar41=PG0, ar42=PL7, ar43=PL6, ar44=PL5, ar45=PL4, ar46=PL3, ar47=PL2, ar48=PL1, ar49=PL0, ar50=PB3, ar51=PB2, ar52=PB1, ar53=PB0, ar54=PF0, ar55=PF1, ar56=PF2, ar57=PF3, ar58=PF4, ar59=PF5,
ar60=PF6, ar61=PF7, ar62=PK0, ar63=PK1, ar64=PK2,
ar65=PK3, ar66=PK4, ar67=PK5, ar68=PK6, ar69=PK7, analog0=PF0, analog1=PF1, analog2=PF2, analog3=PF3, analog4=PF4, analog5=PF5, analog6=PF6, analog7=PF7, analog8=PK0, analog9=PK1, analog10=PK2, analog11=PK3, analog12=PK4, analog13=PK5, analog14=PK6,
analog15=PK7

#*# DO NOT EDIT THIS BLOCK OR BELOW. The contents are auto-generated.

Großartig! Ein Benchy ist der perfekte erste Druck, um deine neue Klipper-Einrichtung zu testen.
Bevor du den Druck startest, musst du sicherstellen, dass dein Drucker optimal eingestellt ist, um Fehler oder Schäden zu vermeiden.

## 1. Wichtige Vorbereitung

⚠️ Z-Offset final einstellen
Da der Drucker noch nicht gedruckt hat, ist dies der allerwichtigste Schritt, um zu verhindern, dass die Düse in das Druckbett kratzt!
1. Homing: Sende G28 in die Konsole.
2. Offset finden: Verwende die manuelle Steuerung, um die Düse so weit abzusenken, bis ein Stück Papier zwischen Düse und Bett leicht hakt.
3. Offset speichern: Wenn du den Wert (z. B. -0.25) gefunden hast, speichere ihn dauerhaft mit:
G-Code


klappt irgenwie doch über die oberfläche

hotend_fan pin: ar7// aber keine power ? 24V oder ? ar5 grüne led
ar6 blaue led
Bauteillüfter pin: ar9

Dann hast du jetzt:
- Hotend-Lüfter und Bauteillüfter korrekt auf eigenen Pins → laufen sauber.
- RGB-SMD-LEDs als [output_pin] → nur an/aus, kein Flackern.
- Makros für LED-Farben bereit → schnelle Kontrolle über GCode. G28
M104 S200
M140 S60
Filament Sensor filament: filament detected 11:26:31
QUERY_FILAMENT_SENSOR SENSOR=filament

PRINT_START BED_TEMP=[first_layer_bed_temperature] EXTRUDER_TEMP=[first_layer_temperature]

END_PRINT

FILAMENT_UNLOADFilament EntladenFunktioniert korrekt: heizt auf 230°C, fährt relativ 100 mm zurück, dann zurück auf absolut (G90).FILAMENT_LOADFilament LadenFunktioniert korrekt: heizt auf 230°C, fährt relativ 125 mm vor, macht einen kleinen Retract von 2 mm und geht dann zurück auf absolut (G90).LED_GRUENLED GrünKorrekt: Schaltet Grün an, Rot und Blau aus.SMART_HOMEHoming mit ParkenLogik-Problem: Führt G28 aus. Direkt danach fährt es auf X3 Y3 Z5 und schaltet die LED grün. Die Park- und LED-Aktion sollte aus diesem Makro entfernt werden, da es nur fürs Homing zuständig sein sollte (siehe Empfehlung unten).FAHRE_AUF_NEUTRALE_POSITIONNeutrale PositionRedundant: Ruft SMART_HOME auf, was bereits parkt. Fährt dann von X3 Y3 Z5 erneut zu
X3 Y3 Z5 und dann zu Z10.

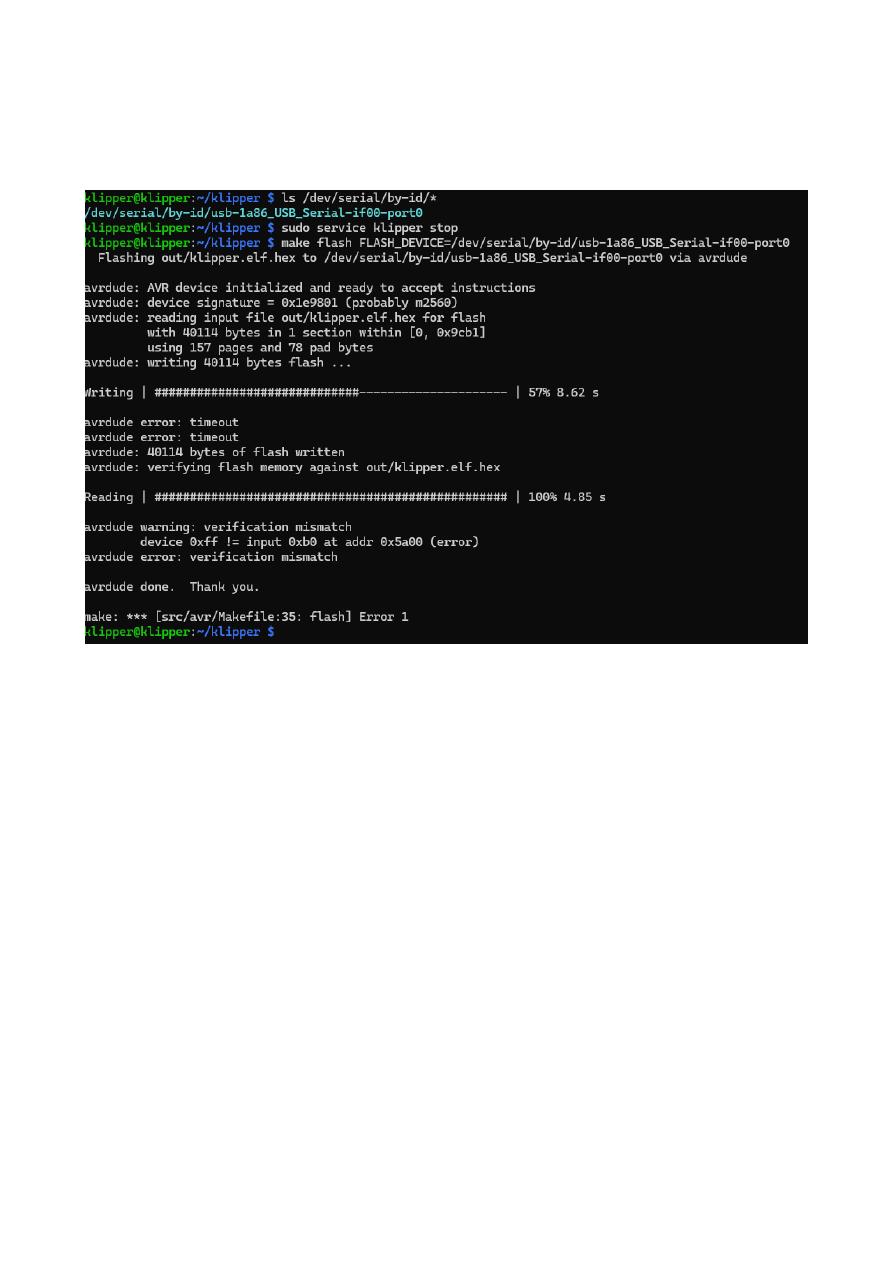
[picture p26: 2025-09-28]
assets/img/klipper doku _convertedToPDF014.png

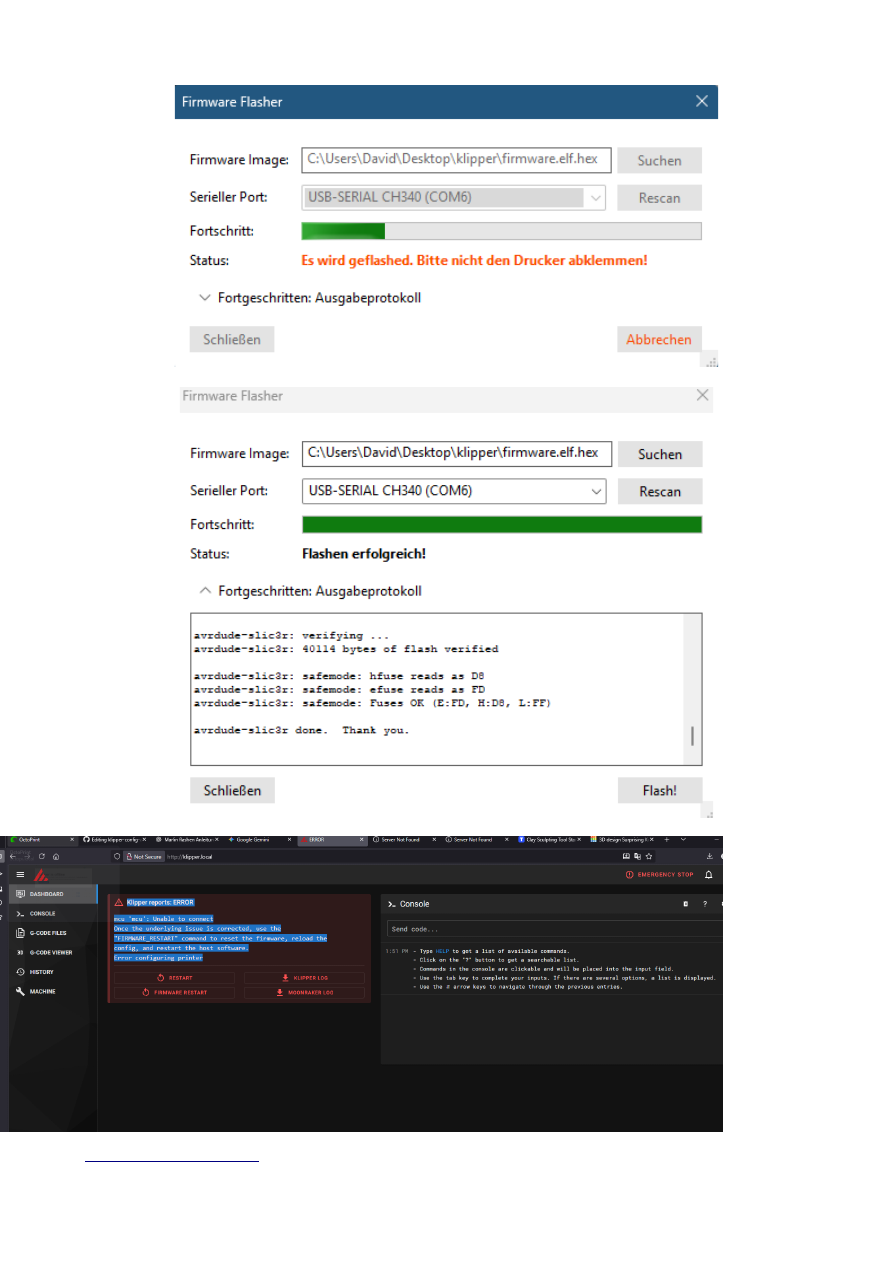
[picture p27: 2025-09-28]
assets/img/klipper doku _convertedToPDF023.png

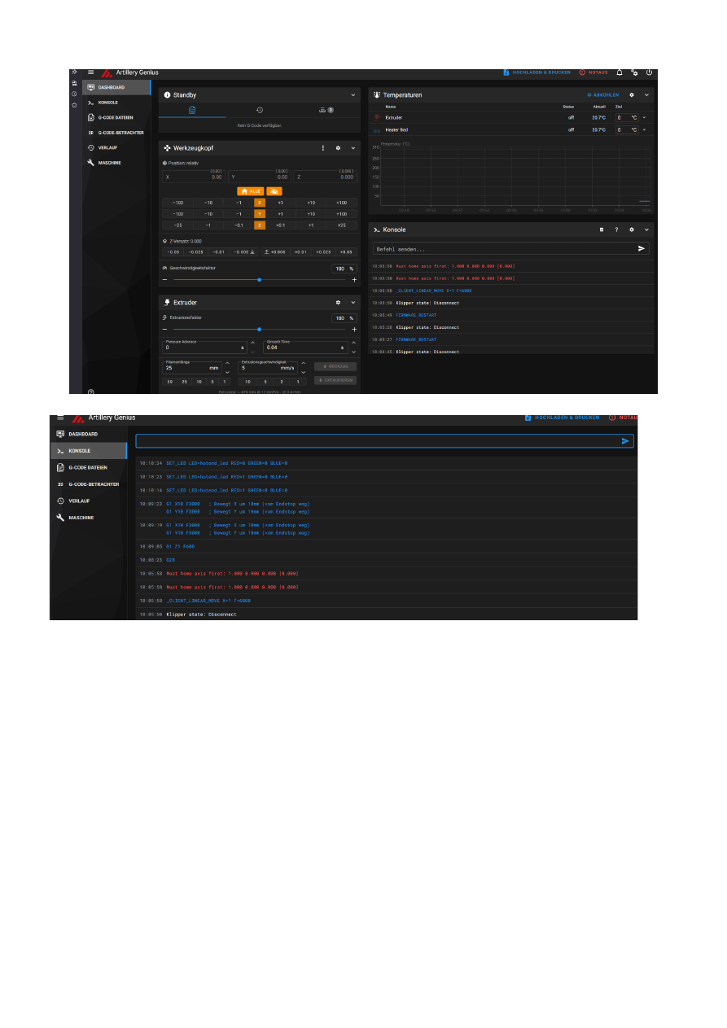
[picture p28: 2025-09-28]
assets/img/klipper doku _convertedToPDF029.png

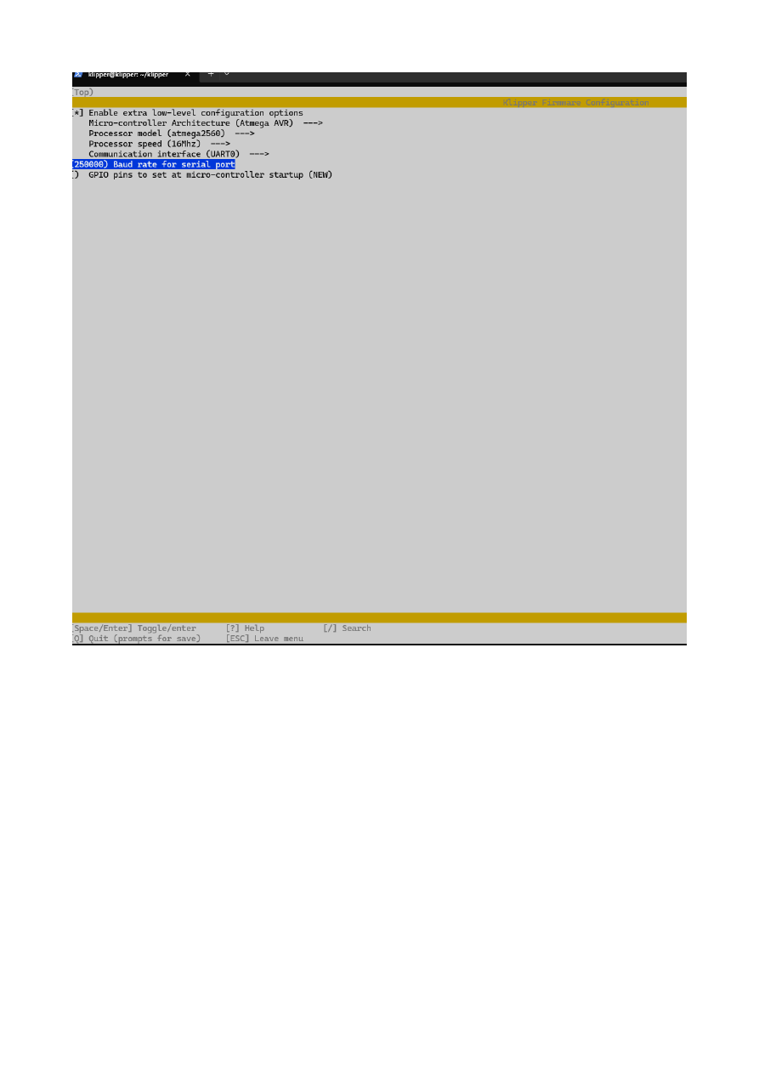
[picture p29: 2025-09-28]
assets/img/klipper doku _convertedToPDF013.png

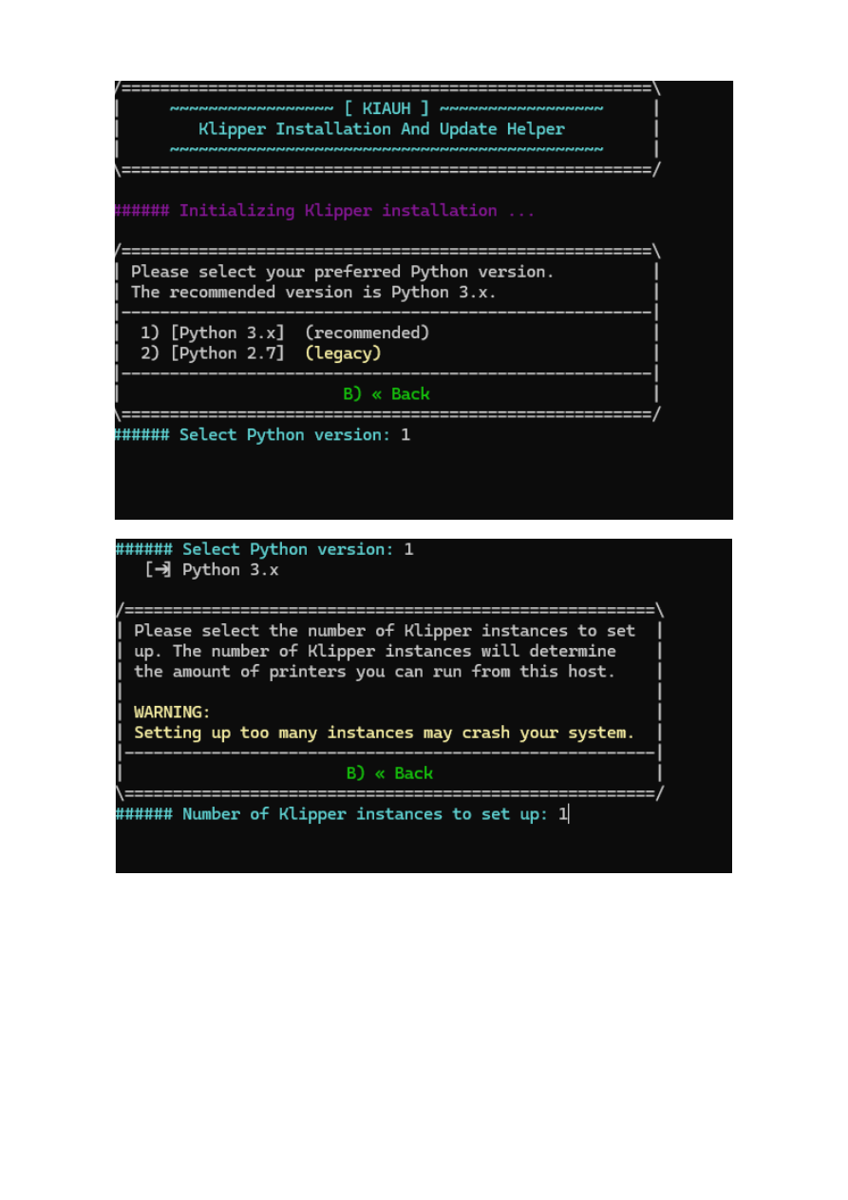
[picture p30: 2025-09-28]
assets/img/klipper doku _convertedToPDF005.png

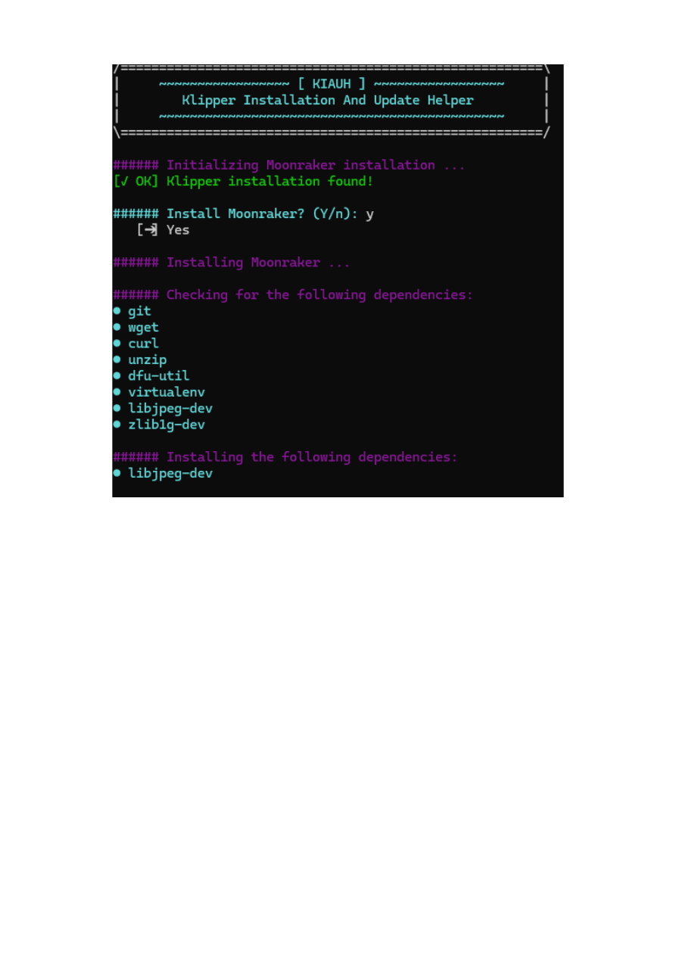
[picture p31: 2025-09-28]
assets/img/klipper doku _convertedToPDF008.png

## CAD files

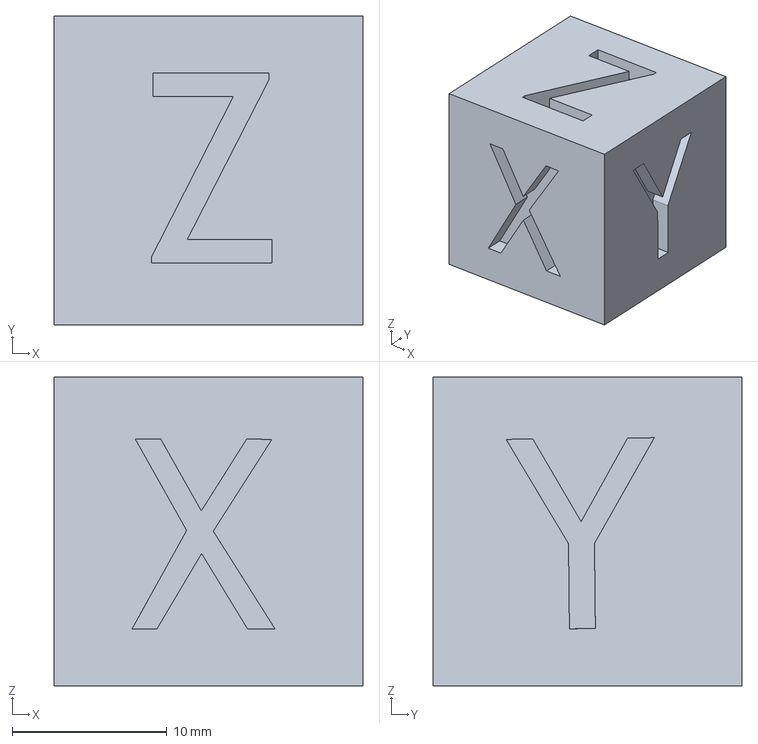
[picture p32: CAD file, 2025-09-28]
Prusa/3d/3mf/xyzCalibration_cube_klipper_flow.3mf
20.0 x 20.0 x 20.0 mm

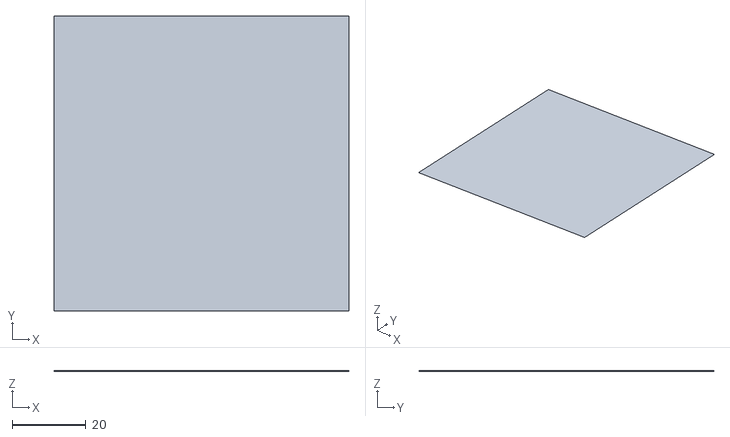
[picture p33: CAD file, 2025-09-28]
Prusa/3d/STL/z-offset-calibration-tool.stl
80.0 x 80.0 x 0.2

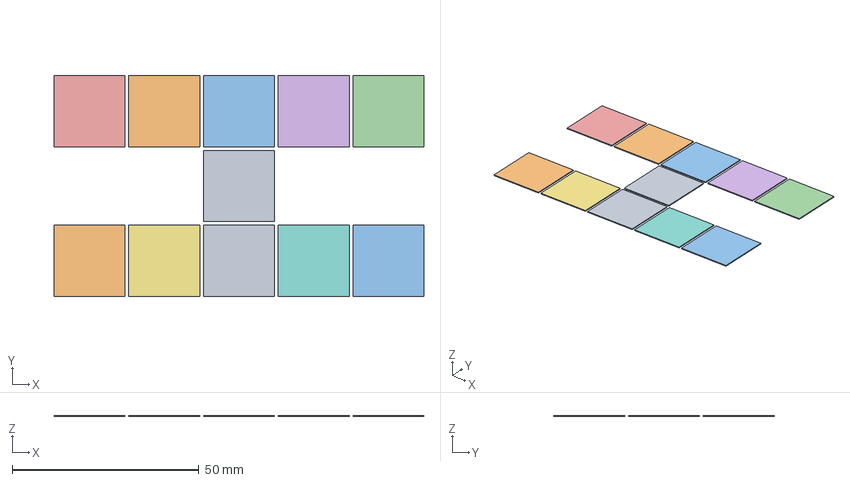
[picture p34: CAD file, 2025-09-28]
Prusa/3d/3mf/z-search.3mf
99.0 x 59.0 x 0.3 mm

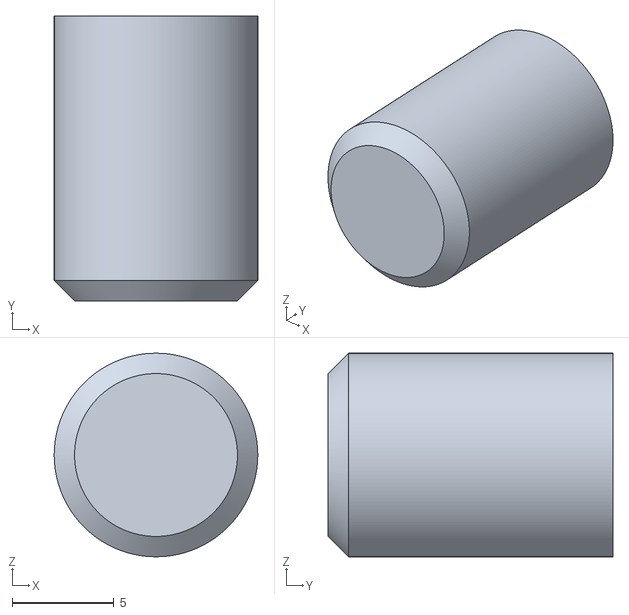
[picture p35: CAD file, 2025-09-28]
Prusa/3d/STL/Small_Round_Peg.stl
10.0 x 14.0 x 10.00

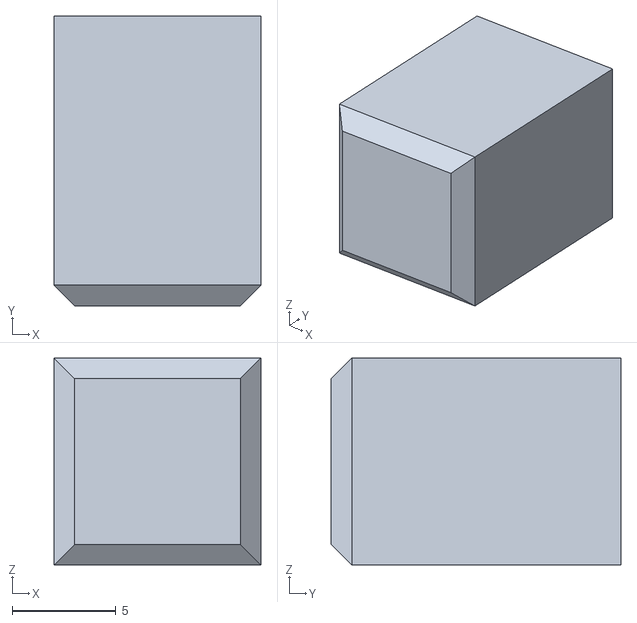
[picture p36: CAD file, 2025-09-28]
Prusa/3d/STL/Small_Square_Peg.stl
10.0 x 14.0 x 10.0

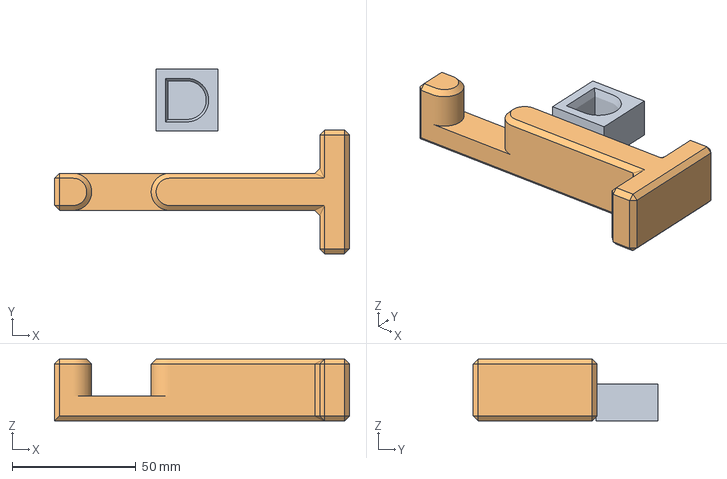
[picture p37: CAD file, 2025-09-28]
Prusa/3d/3mf/xyzCalibration_cube_klipper_XYZ-Achsen-Kalibrierung.3mf
119.0 x 74.5 x 25.0 mm
Halter.stl
Fenster Kippstopper.stl

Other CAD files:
Prusa/3d/3mf/xyzCalibration_cube.3mf

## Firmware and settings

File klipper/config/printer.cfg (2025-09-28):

[gcode_macro SMARTHOME]
gcode:
    LED_GRUEN
    {% if printer.toolhead.homed_axes != "xyz" %}
        G28
    {% endif %}

[gcode_macro MOVE_CENTER]
gcode:
    SMARTHOME
    G90
    G1 Z20 F3000        ; Sicherer Z-Abstand
    G1 X110 Y110 F9000  ; Mitte des Bettes (220x220)
    

[gcode_macro PRINT_BED_CHANGE]
gcode:
    SMARTHOME
    G90
    G1 Z50 F3000        ; Sicherer Z-Abstand
    G1 X220 Y220 F9000  ; Mitte des Bettes (220x220)
    
    G1 Z20 F3000        ; Sicherer Z-Abstand
    

[gcode_macro PID_EXTRUDER]
gcode:
    M106 S255
    {% set TARGET_TEMP = params.TARGET_TEMP|default(210)|float %} 
    PID_CALIBRATE HEATER=extruder TARGET={TARGET_TEMP}

[gcode_macro PID_BED]
gcode:
    {% set TARGET_TEMP = params.TARGET_TEMP|default(60)|float %}
    PID_CALIBRATE HEATER=heater_bed TARGET={TARGET_TEMP}

; === KORRIGIERTE PAUSE/RESUME/CANCEL MAKROS MIT SAVE/RESTORE ===

[gcode_macro PAUSE]
description: Pausiert den Druck sicher
rename_existing: BASE_PAUSE
gcode:
    M400                           ; Alle Bewegungen abschließen
    SAVE_GCODE_STATE NAME=PAUSE_state  ; speichert Z bevor wir hochfahren

    M117 PAUSE - Zeit für Filamentwechsel
    LED_BLAU

    G91
    G1 E-2 F3000
    G1 Z10 F3000                   ; Z leicht anheben für Sicherheit
    G90

    M117 Pausiert - Resume zum Fortsetzen
    BASE_PAUSE


[gcode_macro RESUME]
description: Setzt Druck korrekt fort
rename_existing: BASE_RESUME
gcode:
    M117 RESUME - Fortsetze Druck
    LED_BLAU

    ; Druckposition exakt wiederherstellen
    RESTORE_GCODE_STATE NAME=PAUSE_state

    
    G91
    ;G1 E2 F3000 Optional: kleine Extrusion, um Filament wieder zu primen
    G90

    M117 Druck läuft weiter...
    LED_Weiss

    BASE_RESUME


[gcode_macro CANCEL_PRINT]
description: Bricht den Druck sicher ab
rename_existing: BASE_CANCEL_PRINT
gcode:
    M117 Druck abgebrochen
    LED_ROT

    BASE_CANCEL_PRINT

    TURN_OFF_HEATERS
    M106 S0                         ; Lüfter aus

    G91
    G1 Z10 F3000
    G90
    G1 X0 Y200 F6000                ; Kopf nach vorne (anpassen)

    M117 Druck abgebrochen - Heizer aus

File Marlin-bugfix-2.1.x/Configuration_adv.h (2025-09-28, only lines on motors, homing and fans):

#define E0_AUTO_FAN_PIN 7
#define E1_AUTO_FAN_PIN -1
#define E2_AUTO_FAN_PIN -1
#define E3_AUTO_FAN_PIN -1
#define E4_AUTO_FAN_PIN -1
#define E5_AUTO_FAN_PIN -1
#define E6_AUTO_FAN_PIN -1
#define E7_AUTO_FAN_PIN -1
#define CHAMBER_AUTO_FAN_PIN -1
#define COOLER_AUTO_FAN_PIN -1
#define HOMING_BUMP_MM      { 5, 5, 2 }       // (linear=mm, rotational=°) Backoff from endstops after first bump
#define HOMING_BUMP_DIVISOR { 2, 2, 4 }       // Re-Bump Speed Divisor (Divides the Homing Feedrate)
#define QUICK_HOME                            // If G28 contains XY do a diagonal move first
#define MICROSTEP_MODES { 16, 16, 16, 16, 16, 16 } // [1,2,4,8,16]

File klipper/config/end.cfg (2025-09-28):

[gcode_macro PRINT_END]
gcode:
    M400
    G92 E0
    G91
    G1 E-2 F3000  ; Retract
    G1 Z50 F3000  ; Z um 50 mm anheben
    G90
    
    ; Parkposition (X/Y unverändert, nur Z hoch)
    G1 X110 Y220 F7500
    
    ; Heizung ausschalten
    M104 S0
    M140 S0
    
    ; Lüfter auskühlen lassen
    M106 S128  ; moderate Geschwindigkeit
    G4 S30
    M106 S0
    
    LED_AUS  ; Fertig-Status
    M84
    M117 Druck fertig!

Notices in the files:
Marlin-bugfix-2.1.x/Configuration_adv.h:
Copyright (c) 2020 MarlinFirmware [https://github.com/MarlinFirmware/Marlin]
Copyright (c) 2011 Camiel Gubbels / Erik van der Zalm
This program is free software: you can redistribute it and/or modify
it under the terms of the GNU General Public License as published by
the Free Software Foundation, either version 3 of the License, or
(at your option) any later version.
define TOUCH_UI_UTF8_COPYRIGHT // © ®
